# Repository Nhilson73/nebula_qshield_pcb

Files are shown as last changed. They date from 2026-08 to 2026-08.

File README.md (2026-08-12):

# Nebula Q-Shield® PCB

**Precision Fermentation Monitor** — PCB shield de 4 capas para el Arduino UNO Q, con sensores de fermentación, control de actuadores, HMI UART y trazabilidad integrada al ecosistema Nebula.

Built by [Cafelium SRL](https://github.com/Nhilson73) · Dominican Republic

> **Parte del ecosistema [Nebula Q-Shield — Arduino App Lab](https://github.com/Nhilson73/Nebula_ArduinoAPPLab_UNOQ)**
>
> **Awards:** I+D Lab INDOTEL 2025 · CREE Banreservas 2026 · Pitch4FUN 2026
>
> **Firmware source of truth:** [`Nhilson73/Nebula_ArduinoAPPLab_UNOQ`](https://github.com/Nhilson73/Nebula_ArduinoAPPLab_UNOQ). No usar `Nebula_UNOQ_ArduinoIDE_Core` para validaciones de pinout/hardware.
>
> **Estado actual (2026-08-12):** esquemático validado (ERC 0 violaciones), PCB en KiCad 10.0.5, factor de forma UNO Q inmutable, dimensiones **150 mm × 120 mm** (se amplió el ancho para la propuesta de placement de Gemini Spark), Fase 4 de potencia completa y Fase 5/6 de ruteo en progreso: DRC 0 violaciones, 72 nets desconectados restantes. Se ajustó `Signal_Default` a vía mínima 0.5/0.2 mm para mejorar conectividad GND. Ver `docs/INSIGHT_FABRICATION_ROADMAP.md`.

---

## ¿Qué es el Q-Shield®?

El Q-Shield® es un **PCB shield de 4 capas** que se monta sobre el Arduino UNO Q (STM32U585 MCU + Qualcomm QRB2210 MPU), convirtiendo la placa en un sistema completo de monitoreo y control de fermentación para café y cacao de especialidad.

Se fabrica como **una sola PCB** para los tres tiers. La diferencia entre tiers se logra poblando o dejando en DNP ciertos componentes; el firmware selecciona el tier en tiempo de compilación.

```
┌──────────────────────────────────────────────────────────────────┐
│                    NEBULA Q-SHIELD® PCB v1.0                     │
│                                                                  │
│  ┌──────────────┐  ┌──────────────┐  ┌──────────────────────┐   │
│  │ POTENCIA     │  │  ANALÓGICO    │  │     DIGITAL          │   │
│  │              │  │              │  │                      │   │
│  │ 12 V input   │  │ pH  (A0)     │  │ I2C bus (D20/D21)    │   │
│  │ Buck 12→5 V  │  │ ORP (A1)     │  │ HX711 (D2/D3)        │   │
│  │ LDO 5→3.3 V  │  │ Temp (A2)    │  │ GPS + RTC (I2C)      │   │
│  │ TVS + PTC    │  │ CO2 (A4)     │  │ RS485 bridge (Sig.)  │   │
│  │ Schottky     │  │ DO  (A5)     │  │ HMI UART             │   │
│  └──────────────┘  └──────────────┘  └──────────────────────┘   │
│                                                                  │
│  ┌──────────────────────────────────────────────────────────┐   │
│  │  ACTUADORES (opto-aislados) — Insight+                  │   │
│  │  Recirculación · Solenoide gas · Chiller                 │   │
│  └──────────────────────────────────────────────────────────┘   │
│                                                                  │
│  ┌──────────────────────────────────────────────────────────┐   │
│  │  CONECTOR ARDUINO UNO Q / R3 (32-pin shield header)      │   │
│  └──────────────────────────────────────────────────────────┘   │
└──────────────────────────────────────────────────────────────────┘
```

---

## Hardware Tier Model

Una sola PCB para los 3 tiers — los componentes no poblados (DNP) se seleccionan en fabricación:

| Tier | Sensores / Funciones | Actuadores | Placements poblados |
|---|---|---|---|
| **Essential®** | GPS (altitud), RTC/timestamp, temperatura, pH, ORP, HMI | — | 88 / 163 |
| **Insight®** | Essential + CO₂ (presión), DO, celdas de carga, I2C bus D20/D21 | Recirculación, solenoide gas, chiller | 137 / 163 |
| **Signature®** | Insight + densidad celular total (TCD) + activa (ACD) Hamilton vía RS485 | Igual que Insight | 146 / 163 |

- Convención DNP en el campo `DNP`: lista los tiers en los que el componente **no** se pobla.
- Canal de humedad y válvula PWM de gas quedan eliminados/DNP en todos los tiers.
- El pinout detallado de `J21` está en `docs/INSIGHT_FABRICATION_ROADMAP.md`.

---

## Componentes principales

| # | Componente | Interfaz | Tier |
|---|---|---|---|
| 1 | Sensor pH | Analógico A0 / I2C EZO | Essential+ |
| 2 | Sensor ORP | Analógico A1 / I2C EZO | Essential+ |
| 3 | Sensor temperatura | Analógico A2 | Essential+ |
| 4 | GPS u-blox SAM-M8Q (altitud por GPS) | I2C 0x42 | Essential+ |
| 5 | RTC DS3231 | I2C 0x68 | Essential+ |
| 6 | HMI UART 5" (Nextion/Stone/DWIN) | UART TX/RX | Todos |
| 7 | Celdas de carga + HX711 | Digital D2/D3 | Insight+ |
| 8 | Transductor presión CO₂ | Analógico A4 | Insight+ |
| 9 | Sensor oxígeno disuelto (DO) | Analógico A5 | Insight+ |
| 10 | Driver recirculación (half-bridge) | PWM/DIR D5/D6 | Insight+ |
| 11 | Solenoide gas CO₂/H₂ | GPIO D7 | Insight+ |
| 12 | Chiller (relé opto-aislado) | GPIO D8 | Insight+ |
| 13 | Sensores Hamilton TCD + ACD | RS485/Modbus | Signature |

---

## Diseño 100% Foolproof — 7 Capas de Protección

```
┌─────────────────────────────────────────────────────────┐
│  7. Firmware failsafe (watchdog, store-forward)         │
│  ┌─────────────────────────────────────────────────┐   │
│  │  6. Aislamiento galvánico (ISO7721, PC817)      │   │
│  │  ┌─────────────────────────────────────────┐   │   │
│  │  │  5. Protección térmica (shutdown auto)  │   │   │
│  │  │  ┌─────────────────────────────────┐   │   │   │
│  │  │  │  4. Limitación corriente (PTC)  │   │   │   │
│  │  │  │  ┌─────────────────────────┐   │   │   │   │
│  │  │  │  │  3. ESD/TVS (±8kV)      │   │   │   │   │
│  │  │  │  │  ┌─────────────────┐   │   │   │   │   │
│  │  │  │  │  │  2. Polaridad   │   │   │   │   │   │
│  │  │  │  │  │  ┌─────────┐   │   │   │   │   │   │
│  │  │  │  │  │  │1. Mecán.│   │   │   │   │   │   │
│  │  │  │  │  │  └─────────┘   │   │   │   │   │   │
│  │  │  │  │  └─────────────────┘   │   │   │   │   │
│  │  │  │  └─────────────────────────┘   │   │   │   │
│  │  │  └─────────────────────────────────┘   │   │   │
│  │  └─────────────────────────────────────────┘   │   │
│  └─────────────────────────────────────────────────┘   │
└─────────────────────────────────────────────────────────┘
```

- **Conectores keyed** — Físicamente imposible conectar al revés
- **Schottky SS34** — Protección polaridad inversa sin daño
- **TVS ESD IEC 61000-4-2 Level 4** — ±8 kV contacto, ±15 kV aire
- **PTC recuperable** — Auto-reset después de cortocircuito
- **Thermal shutdown** — Reguladores se apagan a 85°C y se recuperan
- **Opto-aislamiento** — MCU aislado de actuadores de potencia
- **Watchdog dual** — TPS3823 externo (1.6s) + IWDG interno (8s), poblado en TODOS los tiers
- **Aislamiento galvánico on-board** — SN6501 + AMC1301/ISO1541 por canal húmedo (pH, ORP, DO)

---

## Cumplimiento Normativo Europeo

| Directiva | Norma | Estado |
|---|---|---|
| **EMC** (2014/30/EU) | EN 55032 Clase B, EN 61000-4-2/3/4/5/6 | Diseñado |
| **RoHS 3** (2011/65/EU + 2015/863) | Soldadura SAC305, ENIG, sin Pb/Hg/Cd | Especificado |
| **WEEE** (2012/19/EU) | Categoría 6, registro por país | Pendiente registro |
| **RED** (2014/53/EU) | WiFi/BT via Arduino UNO Q cert. | Verificar con Arduino |
| **REACH** ((EC) 1907/2006) | Verificación SVHC proveedores | Pendiente |
| **Marcado CE** | Declaración de Conformidad | Post-ensayos |

---

## Estructura del Repositorio

```
nebula_qshield_pcb/
├── README.md                          # Este documento
├── .gitignore                         # Exclusiones KiCad/OS
│
├── docs/                              # Documentación de ingeniería
│   ├── 01_PCB_ARCHITECTURE.md         # Arquitectura completa del PCB
│   ├── 02_FOOLPROOF_DESIGN.md         # Diseño 100% Foolproof (7 capas)
│   ├── 03_EU_COMPLIANCE.md            # Cumplimiento normativo europeo
│   ├── 04_BOM_PRODUCTION.md           # BOM con part numbers Digi-Key/Mouser
│   ├── 05_POWER_BUDGET.md             # Análisis de presupuesto de potencia
│   ├── 06_PCB_LAYOUT_STACKUP.md       # Guías de layout y stackup 4 capas
│   ├── 07_KICAD_NETLIST.md            # Netlist KiCad y definiciones
│   ├── 08_MECHANICAL_ANALYSIS.md      # Análisis mecánico y compactación
│   ├── INSIGHT_FABRICATION_ROADMAP.md # Hoja de ruta JLCPCB para Insight
│   ├── UNO_Q_FORM_FACTOR.md           # Referencia inmutable del factor de forma UNO Q
│   ├── KICAD10_SSH_SETUP.md           # Guía SSH para clonar desde KiCad 10
│   └── DOCUMENTATION_UPDATE_AUDIT.md  # Auditoría de docs por actualizar
│
├── kicad/                             # Proyecto KiCad 10.0.5
│   ├── nebula_qshield.kicad_pro       # Proyecto principal
│   ├── nebula_qshield.kicad_sch       # Esquemático raíz (jerárquico)
│   ├── nebula_qshield.kicad_pcb       # Layout PCB (en progreso)
│   ├── power_management.kicad_sch     # Sub-hoja: reguladores y protección
│   ├── analog_acquisition.kicad_sch   # Sub-hoja: canales analógicos
│   ├── digital_i2c.kicad_sch          # Sub-hoja: bus I2C, HX711, RS485 bridge
│   ├── actuator_drivers.kicad_sch     # Sub-hoja: drivers de actuadores
│   ├── hmi_connectors.kicad_sch       # Sub-hoja: HMI UART y J21
│   ├── lib/                           # Librerías de símbolos y footprints
│   ├── production/                    # Salidas de fabricación
│   └── UNO_Q_rearchitecture_report.md # Reporte de re-arquitectura UNO Q
│
├── hardware/                          # Diseño mecánico
│   ├── enclosure/                     # Carcasa/enclosure IP54
│   └── cables/                        # Especificaciones de cables
│
├── test/                              # Testing y validación
│   ├── hil/                           # Hardware-in-the-Loop tests
│   └── validation/                    # Reportes de validación
│
└── tools/                             # Scripts Python de automatización
    ├── tier_counts.py                 # Conteos de componentes por tier
    ├── apply_tier_dnp4.py            # Aplicar propiedades DNP por tier
    ├── compare_pcb_to_netlist.py      # Verificar paridad PCB/netlist
    └── update_tier_comments.py       # Actualizar comentarios de tier
```

### Esquemáticos Jerárquicos

```
nebula_qshield.kicad_sch (raíz)
├── power_management.kicad_sch     → 12V protección, Buck 5V, LDO 3.3V, TPS3823 watchdog
├── analog_acquisition.kicad_sch   → pH/ORP/Temp/CO₂/DO + aislamiento galvánico
├── digital_i2c.kicad_sch          → I2C (D20/D21), HX711, RS485 Modbus bridge (Signature)
├── actuator_drivers.kicad_sch     → Recirculación, solenoide gas, chiller
└── hmi_connectors.kicad_sch       → HMI UART y shield header J21
```

---

## Especificaciones Técnicas

| Parámetro | Valor |
|---|---|
| **Dimensiones** | 125 mm × 120 mm (factor de forma Arduino UNO Q inmutable; el tamaño exterior puede variar) |
| **Capas** | 4 (Signal–GND–Power–Signal) |
| **Material** | FR-4 Tg 170°C |
| **Acabado** | ENIG (RoHS) |
| **Cobre** | 1 oz (35 μm) todas las capas |
| **Temperatura operativa** | -10°C a +55°C |
| **Alimentación** | 12V DC (Essential: 2A, Insight: 3A, Signature: 8A) |
| **Placements totales** | 163 (88 Essential / 137 Insight / 146 Signature) |
| **KiCad** | 10.0.5 |
| **IPC Class** | Clase 2 |

---

## Presupuesto de Potencia

| Tier | Potencia continua | Fuente recomendada |
|---|---|---|
| Essential® | 11 W | 12V 2A (24W) |
| Insight® | 23 W | 12V 3A (36W) |
| Signature® | 65 W | 12V 8A (96W) |

---

## Getting Started

### Requisitos

- [KiCad 10.0.5](https://www.kicad.org/download/)
- [Python 3.11+](https://www.python.org/) (para scripts de BOM/CPL)
- Cuenta GitHub con acceso al repositorio

### Clonar el proyecto

Opción A — terminal:

```bash
git clone git@github.com:Nhilson73/nebula_qshield_pcb.git
cd nebula_qshield_pcb/kicad
# Abrir nebula_qshield.kicad_pro con KiCad 10
```

Opción B — desde KiCad 10:

Ver `docs/KICAD10_SSH_SETUP.md` para configurar SSH y clonar directamente desde `File → Clone Project from Git Repository`.

### Validación del diseño

```bash
# ERC
docker run --rm -v "$PWD:/workspace" kicad/kicad:10.0.5 \
  kicad-cli sch erc --severity-all \
  /workspace/kicad/nebula_qshield.kicad_sch

# DRC error-level
docker run --rm -v "$PWD:/workspace" kicad/kicad:10.0.5 \
  kicad-cli pcb drc --severity-error \
  /workspace/kicad/nebula_qshield.kicad_pcb

# Paridad PCB/netlist (exportar primero el netlist XML)
docker run --rm -v "$PWD:/workspace" kicad/kicad:10.0.5 \
  kicad-cli sch export netlist --format kicadxml \
  -o /workspace/kicad/uno_q.xml /workspace/kicad/nebula_qshield.kicad_sch

docker run --rm -v "$PWD:/workspace" kicad/kicad:10.0.5 \
  python3 /workspace/tools/compare_pcb_to_netlist.py
```

### Generar archivos de fabricación

Desde KiCad 10:

```
File → Plot → Gerber
File → Fabrication Outputs → Drill Files
File → Fabrication Outputs → BOM
File → Fabrication Outputs → Footprint Position File
```

Los parámetros de fabricación JLCPCB están en `docs/INSIGHT_FABRICATION_ROADMAP.md` y `docs/04_BOM_PRODUCTION.md`.

---

## Pinout J21 de referencia (Insight)

| Pin | Función | Net |
|-----|---|-----|
| 1 | BOOT | NC |
| 2 | IOREF | NC |
| 3 | ~RESET | `/MCU_NRST` |
| 4 | +3V3 | `/3V3_RAIL` |
| 5 | +5V | `/5V_RAIL` |
| 6 | GND | `GND` |
| 7 | GND2 | `GND` |
| 8 | VIN | `/12V_RAIL` |
| 9 | A0/D14 | `/PH_ADC` |
| 10 | A1/D15 | `/ORP_ADC` |
| 11 | A2/D16 | `/TEMP_ADC` |
| 12 | A3/D17 | `/HUM_ADC` — DNP all tiers |
| 13 | A4/D18 | `/CO2_ADC` |
| 14 | A5/D19 | `/DO_ADC` |
| 15 | D0 | `/HMI_RX` |
| 16 | D1 | `/HMI_TX` |
| 17 | D2 | `/HX711_DOUT` |
| 18 | D3 | `/HX711_SCK` |
| 19 | D4 | `/MCU_WDI` |
| 20 | D5 | `/PUMP_PWM` |
| 21 | D6 | `/PUMP_DIR` |
| 22 | D7 | `/CO2_SOL_CTL` |
| 23 | D8 | `/CHILLER_CTL` |
| 24 | D9 | `/CO2_PWM` — DNP all tiers |
| 25 | D10 | `/RS485_IRQ` |
| 26 | D11 | NC |
| 27 | D12 | NC |
| 28 | D13 | `/LED_STATUS` |
| 29 | GND | `GND` |
| 30 | AREF | NC |
| 31 | D20/SDA | `/I2C_SDA` |
| 32 | D21/SCL | `/I2C_SCL` |

El pinout completo, mapa de tiers y hoja de ruta de fabricación están en `docs/INSIGHT_FABRICATION_ROADMAP.md`.

---

## Repositorios Relacionados

| Repositorio | Descripción |
|---|---|
| [Nebula_ArduinoAPPLab_UNOQ](https://github.com/Nhilson73/Nebula_ArduinoAPPLab_UNOQ) | Firmware MCU + Software MPU + Servicios Docker + Contratos L2. **Source of truth** para el pinout y lógica del Q-Shield. |
| **nebula_qshield_pcb** (este repo) | PCB shield para Arduino UNO Q (esquemáticos KiCad, BOM, compliance) |

---

## Licencia

Proprietary — Cafelium SRL. All rights reserved.

---

## Team

- **Nhilson** — Lead Architect
- **Drancés** — Co-founder
- **Alfredo** — Co-founder

Powered by the **Nebula Ecosystem™**: Nebula Terra® · Nebula Fermentation® · Nebula Originblok® · Nebula Marketplace®

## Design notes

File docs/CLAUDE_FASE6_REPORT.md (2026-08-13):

# Reporte Claude Code — Fase 6: cierre de desconectados y descongestión del bloque analógico

## Resumen ejecutivo

| | Antes | Después |
|---|---|---|
| Tamaño de board | 150 × 120 mm | **170 × 120 mm** |
| DRC violations | 0 | **0** |
| ERC violations | 0 | **0** |
| Unconnected items | 38 | **69** (ver por qué subió, abajo) |
| Bloque analógico | ~34×32 mm, ~59 componentes | reubicado en ~2 mm de aire real vs. 0.25 mm antes |

El pedido original eran los 38 pares desconectados que quedaron después de 8 rondas previas de scripts (`close_pairs_v4`…`v8`, ruteo manual de GND). Diagnostiqué que la mayoría de esos 38 no eran un problema de ruteo sino de **geometría real**: varios pads quedaban encajonados entre pines vecinos de otros componentes con ~0.25–0.45 mm de separación, insuficiente incluso para el ancho **mínimo legal del board**. No hay ruta, por más inteligente que sea el router, que entre ahí sin más aire o sin mover algo.

Con tu autorización moví el tamaño del board a 170×120 mm y reubiqué el bloque analógico completo (~59 componentes: T1–T3, U4–U13, R7–R18, R30–R33, D3–D8, D19–D24, C12–C24, C28–C30, TP1–TP2). Eso obligó a **rip-up y re-ruteo de las 183 conexiones** de ese bloque (no solo las 38 originales), porque mover un componente invalida todo el copper que ya tenía. De esas 183, el script cerró **117 (64%)** manteniendo DRC en 0 en todo momento; quedan **66 desconectadas del bloque analógico** más **3 de fuera de ese alcance** (69 total) — ver detalle abajo.

## Qué se entrega

1. **`tools/route_fase6.py`** — router propio (Dijkstra sobre grilla local F.Cu/B.Cu + transición por vía, con verificación geométrica exacta antes de comprometer cualquier track/vía) para cerrar pares `unconnected_items` reportados por `kicad-cli pcb drc`. Reemplaza la heurística de esquinas de `close_pairs_v8.py`, que se había estancado en los 38 pares sin poder avanzar más. Incluye:
   - Fallback a ancho reducido ("neck-down") cuando el ancho de netclass no entra, respetando el **mínimo real por netclass** de `kicad/nebula_qshield.kicad_dru` (no un piso genérico) — Power/HighCurrent nunca bajan de 0.5 mm, Analog/I2C no bajan de 0.25 mm, etc.
   - Fase de nudge (≤2 mm) de pasivos analógicos (`C20,C21,C23,R30,R31,R32`) con reconexión por jumper del pin que ya tenía copper — implementada pero en la práctica no tuvo éxito en ningún caso probado: el encajonamiento excede 2 mm en los casos donde se necesitaba.
   - Filtra pares `Zone`↔`Zone` que `kicad-cli` reporta de forma no determinística (ligado al orden de relleno de islas de plano) sin coordenada real de conexión.
   - Uso: `<python de KiCad> tools/route_fase6.py [board.kicad_pcb] [--dry-run] [--verbose]`. Corrido varias veces sobre el mismo board sigue cerrando pares adicionales (cada pasada reduce algo la congestión para la siguiente).

2. **`tools/replan_analog_block.py`** — script de re-layout:
   - Extiende `Edge.Cuts` y las 2 zonas full-board (GND en 2 capas, `/12V_RAIL`) 20 mm a la derecha (150.1 → 170.1 mm).
   - **No desplaza** la columna de conectores J2/J3/J5/J15–J19 ni el sector de relés/actuadores (K1, K2, U17, U20…): entre el bloque analógico y esa columna pasan ~7 nets ajenas (bus RS485, interfaz HX711) a distintas alturas; moverla hubiera obligado a re-rutear todo eso también, muy por fuera del pedido.
   - Reempaquetado (shelf-packing por tamaño descendente) del bloque analógico en un corredor en **forma de L**: franja superior (como antes, arriba del courtyard de J21) + franja angosta a la derecha del courtyard de J21 (que es el área de acoplamiento UNO Q, inmutable) hasta antes de J16/J17/D10. Separación entre componentes 2–4× la que tenían antes (0.4–1.2 mm según tamaño, vs. ~0.25 mm).
   - Rip-up de: todo el copper propio de las ~48 nets del bloque analógico; la porción local de GND/`/3V3_RAIL`/`/5V_RAIL`/`/12V_RAIL` dentro del área vieja/nueva del cluster; y los tracks de paso (`HX711_EN/EP/SP`, `HX711_DOUT`, `RS485_A/B`, `MOTOR_VS`, `I2C_SCL`) que cruzaban el nuevo corredor.
   - Uso: `<python de KiCad> tools/replan_analog_block.py [board.kicad_pcb]`.

3. `kicad/nebula_qshield.kicad_pcb` modificado: 170×120 mm, bloque analógico reubicado, 117 de 183 conexiones de ese bloque re-ruteadas, **0 violaciones DRC**.

## Validación

```
kicad-cli pcb drc --severity-error --refill-zones -o kicad/nebula_qshield-drc.rpt kicad/nebula_qshield.kicad_pcb
  → Found 0 violations
  → Found 69 unconnected items

kicad-cli sch erc --severity-all -o kicad/nebula_qshield-erc.rpt kicad/nebula_qshield.kicad_sch
  → Found 0 violations
```

(Corrido con `kicad-cli.exe` 10.0.5 local — mismo binario que la imagen `kicad/kicad:10.0.5`; no hizo falta Docker en este entorno Windows.)

## Por qué el número de desconectados subió de 38 a 69 en vez de bajar a 0

No es una regresión: mover cualquier componente invalida **todo** el copper que tenía, no solo el que estaba roto. Al reubicar el bloque analógico completo, las 183 conexiones de esas ~48 nets quedaron sin rutear (no solo las 38 que ya estaban rotas) y hubo que re-hacerlas desde cero con el layout nuevo. El router cerró 117 de esas 183 (64%) sin generar ninguna violación DRC en el proceso — corrí el ciclo completo 3 veces sobre el board real; la tercera pasada ya no cerró ninguna adicional (estancamiento).

## Los 69 que quedan — desglose y causa raíz

**66 dentro del bloque analógico recién reubicado** (`/Analog Acquisition/*`, más `GND`/`/3V3_RAIL`/`/5V_RAIL`/`/12V_RAIL` locales a ese bloque): la causa dominante es que el corredor en L tiene un **"cuello de botella"** entre la franja superior (filas de T1–T3, U4–U13) y la franja inferior derecha (R30–33, C12–C24, D19–D24) — son ~18 mm de ancho entre el courtyard de J21 y J5/J16/J17. El empaquetador ordenó los componentes por tamaño (para que entraran los 59), no por qué net comparten con qué vecino, así que varias conexiones terminaron necesitando cruzar ese cuello de botella en vez de quedar entre componentes contiguos. Ejemplos: `T1↔D19/D20`, `T2↔U8`, `U6↔U4`, varios `RX_FILT`/`RX_SIG`/`GND_ISO_*` entre la fila de arriba y la de abajo.

**Recomendación concreta:** un empaquetador que agrupe por conectividad (ej. cada transformador T*junto con su AMC1301/diodos asociados en la misma sub-región) en vez de solo por tamaño reduciría esto sustancialmente. No lo implementé por tiempo — el packing actual (`pack_cluster` en `replan_analog_block.py`) es un buen punto de partida para iterar: la función ya soporta regiones múltiples, solo falta una heurística de agrupamiento consciente de netlist antes del sort por tamaño.

**3 fuera del bloque analógico, con atención más urgente** (son subsistemas que no pedían tocar, pero `replan_analog_block.py` tuvo que ripear el tramo que cruzaba el nuevo corredor):
- `/Digital & I2C/RS485_B` — bus RS485.
- `/Digital & I2C/HX711_SP`, `/Digital & I2C/HX711_EN` — interfaz de la celda de carga HX711.
- (`HX711_EP` y `HX711_DOUT` sí volvieron a cerrar en el proceso; `HX711_SP`/`EN`/`RS485_B` no.)

Estas tres no son "difíciles" geométricamente — simplemente no llegó a intentarlas con éxito en las 3 pasadas antes de estancarse. Correr `tools/route_fase6.py` una vez más (o revisar a mano esos 3 tramos, son tracks largos y rectos en un área relativamente despejada) debería cerrarlas sin drama.

**Del set original de 38, siguen sin cerrar 4** (genuinamente difíciles, no relacionadas con el bloque analógico):
- `/Actuator Drivers/MOTOR_HO` (Q1↔U17): la misma limitación geométrica de siempre, sin espacio extra ahí porque no se tocó esa zona.
- `/CO2_SOL_CTL` (J21↔R26) y `/I2C_SCL` (R37↔J21): rutas largas cerca del header J21, empeoradas por la congestión del área que sigue igual (no es parte del bloque analógico que se reubicó).
- `/3V3_RAIL` (U22 pad 14): el caso que documenté en detalle — el pad queda a 0.45 mm de los pines vecinos del mismo chip (RS485_RO/XTAL1) en ambas direcciones verticales, y `/3V3_RAIL` es netclass **Power**, que exige mínimo 0.5 mm de ancho por regla custom (`Power_Rails` en el `.kicad_dru`) — ni con neck-down entra. Requiere mover el footprint de `U22` (fuera del alcance permitido) o aceptar una excepción de ancho documentada explícitamente en el design rule.

## Notas para quien continúe

- El corredor en L está documentado con sus 4 esquinas exactas en `replan_analog_block.py` (`REGION_1`, `REGION_2`) — están ajustadas al milímetro contra los courtyards reales de J21/J2/J3/J5/J16/J17/D10 (los descubrí por prueba y error, varias iteraciones dieron falsos "courtyard overlap" hasta calzar los márgenes). No los toques sin volver a chequear esos courtyards.
- `tools/route_fase6.py` es reutilizable tal cual para cualquier ronda futura de cierre — solo necesita un `.kicad_pcb` + su `.kicad_pro`/`.kicad_dru` con el mismo nombre base al lado (para que `kicad-cli` resuelva las reglas custom del proyecto).
- **Importante para testing**: si copiás el `.kicad_pcb` a otro nombre para probar, copiá también el `.kicad_pro` y el `.kicad_dru` con el mismo basename — si no, `kicad-cli` aplica reglas genéricas de KiCad en vez de las custom del proyecto y reporta violaciones falsas (así lo descubrí: 217 violaciones falsas por esto en una prueba temprana).

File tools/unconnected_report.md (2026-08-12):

# Análisis de nets desconectadas
**Total pares:** 40

## Resumen por red
| Net | Pares |
| --- | --- |
| GND | 5 |
| /12V_RAIL | 5 |
| /5V_RAIL | 4 |
| /3V3_RAIL | 2 |
| /Analog Acquisition/VDD_ISO_ORP | 2 |
| /Analog Acquisition/PH_ATT | 2 |
| /Analog Acquisition/ORP_ATT | 1 |
| /HUM_ADC | 1 |
| /CO2_SOL_CTL | 1 |
| /Analog Acquisition/GND_ISO_PH | 1 |
| /Analog Acquisition/ORP_SIG | 1 |
| /I2C_SCL | 1 |
| /Analog Acquisition/PH_BUF | 1 |
| /Analog Acquisition/VDD_ISO_PH | 1 |
| /Analog Acquisition/VDD_ISO_DO | 1 |
| /Analog Acquisition/DO_FILT | 1 |
| /Actuator Drivers/MOTOR_HO | 1 |
| /Analog Acquisition/DO_SEC_B | 1 |
| /Analog Acquisition/CO2_SIG | 1 |
| /Analog Acquisition/DO_BUF | 1 |
| /Analog Acquisition/DO_SIG | 1 |
| /Analog Acquisition/SN_D1_DO | 1 |
| /Analog Acquisition/SN_D2_DO | 1 |
| /Analog Acquisition/SN_D1_ORP | 1 |
| /Analog Acquisition/SN_D2_ORP | 1 |
| /Analog Acquisition/SN_D2_PH | 1 |

## Detalle de pares (Net, Tipo_A, Ref_A, Capa_A, x_A, y_A -> Tipo_B, Ref_B, Capa_B, x_B, y_B)
| Net | A | Ref A | Capa A | xA | yA | B | Ref B | Capa B | xB | yB |
| --- | --- | --- | --- | --- | --- | --- | --- | --- | --- | --- |
| /Analog Acquisition/ORP_ATT | Pad 1 | R32 | F.Cu | 71.82 | 31.87 | Track | None | B.Cu | 67.0102 | 35.1403 |
| /HUM_ADC | Pad 1 | C23 | F.Cu | 71.83 | 33.11 | Track | None | F.Cu | 65.07 | 31.87 |
| GND | Via | None | F.Cu - B.Cu | 4.4598 | 25.9154 | Pad 2 | C11 | F.Cu | 3.79 | 24.86 |
| GND | Via | None | F.Cu - B.Cu | 63.6826 | 19.1636 | Pad 5 | U9 | F.Cu | 65.505 | 20.875 |
| GND | Pad 2 | C21 | F.Cu | 68.29 | 33.11 | Track | None | F.Cu | 71.2772 | 33.8472 |
| GND | Track | None | F.Cu | 72.79 | 33.11 | Pad 2 | C14 | F.Cu | 75.04 | 32.11 |
| GND | Pad 2 | D5 | F.Cu | 89.35 | 21.9 | Track | None | F.Cu | 88.185 | 26.0062 |
| /3V3_RAIL | Pad 14 | U22 | F.Cu | 22.8625 | 104.025 | Via | None | F.Cu - B.Cu | 21.6224 | 104.1817 |
| /3V3_RAIL | Track | None | F.Cu | 67.445 | 22.1518 | Via | None | F.Cu - B.Cu | 72.3983 | 23.2477 |
| /Analog Acquisition/VDD_ISO_ORP | Via | None | F.Cu - B.Cu | 70.35 | 28.55 | Pad 1 | U9 | F.Cu | 61.695 | 25.825 |
| /Analog Acquisition/VDD_ISO_ORP | Via | None | F.Cu - B.Cu | 70.35 | 28.55 | Via | None | F.Cu - B.Cu | 84.3898 | 28.5614 |
| /CO2_SOL_CTL | PTH pad 22 | J21 | F.Cu - B.Cu | 41.66 | 86.36 | Via | None | F.Cu - B.Cu | 105.0 | 95.51 |
| /Analog Acquisition/GND_ISO_PH | Track | None | F.Cu | 85.54 | 31.86 | Via | None | F.Cu - B.Cu | 69.57 | 31.87 |
| /Analog Acquisition/ORP_SIG | Via | None | F.Cu - B.Cu | 78.57 | 20.12 | Track | None | F.Cu | 89.6 | 20.6 |
| /I2C_SCL | Pad 1 | R37 | F.Cu | 68.055 | 96.0 | Track | None | B.Cu | 68.58 | 86.36 |
| /Analog Acquisition/PH_BUF | Via | None | F.Cu - B.Cu | 68.34 | 31.87 | Track | None | F.Cu | 83.1227 | 11.825 |
| /Analog Acquisition/VDD_ISO_PH | Track | None | F.Cu | 83.695 | 20.0977 | Track | None | F.Cu | 64.2719 | 27.4719 |
| /5V_RAIL | Via | None | F.Cu - B.Cu | 41.0 | 1.3 | Track | None | F.Cu | 19.4 | 7.87 |
| /5V_RAIL | Track | None | F.Cu | 84.8125 | 21.9 | Track | None | F.Cu | 78.05 | 18.05 |
| /5V_RAIL | Via | None | F.Cu - B.Cu | 85.1261 | 24.8836 | Track | None | F.Cu | 84.8125 | 21.9 |
| /5V_RAIL | Via | None | F.Cu - B.Cu | 91.7685 | 26.4338 | Track | None | F.Cu | 85.1261 | 24.8836 |
| /Analog Acquisition/VDD_ISO_DO | Track | None | F.Cu | 75.35 | 30.05 | Track | None | F.Cu | 64.9261 | 33.2639 |
| /Analog Acquisition/DO_FILT | Track | None | F.Cu | 78.58 | 32.86 | Track | None | F.Cu | 69.57 | 30.62 |
| /Actuator Drivers/MOTOR_HO | Via | None | F.Cu - B.Cu | 110.4135 | 68.7984 | Pad 7 | U17 | F.Cu | 117.0714 | 75.1659 |
| /12V_RAIL | Zone | None | In2.Cu | -8.0 | -2.0 | Via | None | F.Cu - B.Cu | -8.0 | -2.0 |
| /12V_RAIL | Pad 1 | R4 | F.Cu | 2.82 | 22.37 | Track | None | F.Cu | 7.3441 | 24.4989 |
| /12V_RAIL | Via | None | F.Cu - B.Cu | 10.225 | 24.0 | Track | None | F.Cu | 14.925 | 23.4563 |
| /12V_RAIL | Track | None | F.Cu | 14.925 | 23.4563 | Via | None | F.Cu - B.Cu | 14.4 | 20.15 |
| /12V_RAIL | Zone | None | In2.Cu | -8.0 | -2.0 | Zone | None | In2.Cu | -8.0 | -2.0 |
| /Analog Acquisition/DO_SEC_B | Pad 6 | T3 | F.Cu | 75.51 | 6.81 | Via | None | F.Cu - B.Cu | 63.65 | 31.1 |
| /Analog Acquisition/CO2_SIG | Via | None | F.Cu - B.Cu | 89.0 | 24.1 | Via | None | F.Cu - B.Cu | 75.07 | 27.87 |
| /Analog Acquisition/PH_ATT | Pad 2 | R31 | F.Cu | 70.59 | 31.87 | Track | None | B.Cu | 68.955 | 29.87 |
| /Analog Acquisition/PH_ATT | Pad 2 | R31 | F.Cu | 70.59 | 31.87 | Pad 2 | U6 | F.Cu | 84.965 | 19.575 |
| /Analog Acquisition/DO_BUF | Pad 2 | U13 | F.Cu | 80.215 | 27.325 | Track | None | F.Cu | 74.465 | 20.875 |
| /Analog Acquisition/DO_SIG | Track | None | F.Cu | 89.35 | 27.6 | Pad 1 | R13 | F.Cu | 67.32 | 30.62 |
| /Analog Acquisition/SN_D1_DO | Via | None | F.Cu - B.Cu | 56.2625 | 30.05 | Via | None | F.Cu - B.Cu | 75.71 | 18.55 |
| /Analog Acquisition/SN_D2_DO | Via | None | F.Cu - B.Cu | 80.39 | 18.05 | Pad 5 | U12 | F.Cu | 58.3375 | 28.15 |
| /Analog Acquisition/SN_D1_ORP | Via | None | F.Cu - B.Cu | 66.26 | 18.05 | Pad 3 | U8 | F.Cu | 84.8125 | 27.55 |
| /Analog Acquisition/SN_D2_ORP | Pad 5 | U8 | F.Cu | 87.0875 | 25.65 | Track | None | F.Cu | 71.34 | 18.05 |
| /Analog Acquisition/SN_D2_PH | Pad 5 | U5 | F.Cu | 87.0875 | 21.9 | Pad 3 | T1 | F.Cu | 62.09 | 18.05 |

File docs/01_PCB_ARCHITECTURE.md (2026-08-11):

# Nebula Q-Shield® — Arquitectura PCB Completa

> **Estado (2026-08-11):** board 125 × 120 mm, DRC/ERC 0, 47 nets desconectadas en Fase 5. Ver `docs/INSIGHT_FABRICATION_ROADMAP.md`.
>
> **Documento:** NQS-ARCH-001 · **Rev:** 1.0 · **Fecha:** Mayo 2026
>
> **Clasificación:** Ingeniería — Diseño de Hardware
>
> **Normativas aplicables:** IPC-2221B, IPC-7351C, IEC 61010-1, EN 61326-1

---

## 1. Especificaciones Generales del PCB

### 1.1 Parámetros Físicos

| Parámetro | Valor | Justificación |
|---|---|---|
| **Dimensiones** | 125 × 120 mm (puede variar) | Factor de forma para acople con Arduino UNO Q; el patrón UNO Q es inmutable |
| **Capas** | 4 (Signal–GND–Power–Signal) | EMC Clase B, aislamiento analógico/digital |
| **Espesor total** | 1.6 mm ± 10% | Estándar IPC-2221B |
| **Material base** | FR-4 Tg 170°C (IT-180A o equivalente) | Operación hasta +55°C ambiente |
| **Acabado superficial** | ENIG (Electroless Nickel Immersion Gold) | RoHS, soldabilidad, longevidad |
| **Máscara de soldadura** | Verde LPI, ambos lados | Estándar industrial |
| **Serigrafía** | Blanca, ambos lados | Identificación de componentes |
| **Peso de cobre** | 1 oz (35 μm) capas externas, 1 oz internas | Capacidad de corriente actuadores |
| **Ancho mín. de pista** | 0.2 mm (señal), 0.5 mm (potencia) | IPC Clase 2 |
| **Espacio mín. entre pistas** | 0.2 mm (señal), 0.3 mm (potencia) | IPC-2221B clearance |
| **Taladro mínimo** | 0.3 mm (vías), 0.8 mm (THT) | Fabricación estándar |
| **Impedancia controlada** | No requerida (señales < 1 MHz) | Frecuencias bajas |

### 1.2 Stackup de 4 Capas

```
┌────────────────────────────────────────────────────────────┐
│  CAPA 1 (TOP)   — Señales + Componentes SMD               │  35 μm Cu
├────────────────────────────────────────────────────────────┤
│  Prepreg 7628   — 0.2 mm                                   │  Dieléctrico
├────────────────────────────────────────────────────────────┤
│  CAPA 2 (GND)   — Plano de tierra continuo                 │  35 μm Cu
├────────────────────────────────────────────────────────────┤
│  Core FR-4      — 0.8 mm                                   │  Dieléctrico
├────────────────────────────────────────────────────────────┤
│  CAPA 3 (PWR)   — Planos de potencia (12V, 5V, 3.3V)      │  35 μm Cu
├────────────────────────────────────────────────────────────┤
│  Prepreg 7628   — 0.2 mm                                   │  Dieléctrico
├────────────────────────────────────────────────────────────┤
│  CAPA 4 (BOT)   — Señales + Componentes SMD               │  35 μm Cu
└────────────────────────────────────────────────────────────┘
         Espesor total: ~1.6 mm
```

**Justificación del plano GND continuo (Capa 2):**
- Retorno de corriente de baja impedancia para todas las señales analógicas
- Blindaje electromagnético entre señales TOP y planos de potencia
- Reducción de EMI radiada para cumplimiento EN 55032 Clase B

---

## 2. Bloques Funcionales

### 2.1 Bloque de Potencia (Power Management)

#### 2.1.1 Entrada de Alimentación 12V DC

```
                            Foolproof Chain
    JACK DC 12V ──►[D_TVS SMAJ15A]──►[F1 PTC 3A]──►[D_SCHOTTKY SS34]──► 12V_RAIL
                    Protección        Fusible          Polaridad
                    transitorio       recuperable      inversa
                    ±15V clamp        I_hold=1.1A      V_f=0.5V
                                      I_trip=2.2A
```

| Componente | Referencia | Valor | Encapsulado | Función |
|---|---|---|---|---|
| D1 | SMAJ15A | 15V TVS bidireccional | SMA | Protección transitorio/ESD entrada |
| F1 | MF-MSMF110 | PTC 1.1A hold / 2.2A trip | 1812 | Fusible recuperable sobrecorriente |
| D2 | SS34 | Schottky 3A 40V | SMA | Protección polaridad inversa |
| C1 | Cerámico MLCC | 100 μF / 25V | 1210 | Desacoplo entrada |
| C2 | Electrolítico | 470 μF / 25V | Ø10×12.5 | Reserva energética transitoria |

#### 2.1.2 Regulador 5V — Buck Converter

```
    12V_RAIL ──►[TPS54302 Buck]──► 5V_RAIL (3A max)
                  │
                  ├── L1: 4.7 μH / 4A (Würth 744043004700)
                  ├── C_in: 22 μF × 2 ceramics (X5R, 25V)
                  ├── C_out: 47 μF × 2 ceramics (X5R, 10V)
                  ├── R_top: 100 kΩ (feedback divider)
                  ├── R_bot: 24.9 kΩ (Vout = 0.596 × (1 + R_top/R_bot) ≈ 5.0V)
                  └── C_boot: 100 nF (bootstrap)
```

| Componente | Referencia | Valor | Encapsulado | Función |
|---|---|---|---|---|
| U1 | TPS54302DDCR | Buck 3A, 4.5–28V in | SOT-23-6 | Regulador 12V → 5V |
| L1 | 744043004700 | 4.7 μH / 4A sat | 4×4×2 mm | Inductor de potencia |
| C3, C4 | X5R 25V | 22 μF | 0805 | Capacitor entrada buck |
| C5, C6 | X5R 10V | 47 μF | 0805 | Capacitor salida buck |
| R1 | — | 100 kΩ ±1% | 0402 | Feedback superior |
| R2 | — | 24.9 kΩ ±1% | 0402 | Feedback inferior |
| C7 | — | 100 nF | 0402 | Bootstrap |

#### 2.1.3 Regulador 3.3V — LDO

```
    5V_RAIL ──►[AMS1117-3.3]──► 3.3V_RAIL (800 mA max)
                  │
                  ├── C_in: 10 μF ceramic (X5R, 10V)
                  └── C_out: 22 μF ceramic (X5R, 10V) + 10 μF tantálum
```

| Componente | Referencia | Valor | Encapsulado | Función |
|---|---|---|---|---|
| U2 | AMS1117-3.3 | LDO 3.3V / 800 mA | SOT-223 | Regulador 5V → 3.3V |
| C8 | X5R 10V | 10 μF | 0805 | Desacoplo entrada LDO |
| C9 | X5R 10V | 22 μF | 0805 | Estabilidad salida LDO |
| C10 | Tantálum | 10 μF / 10V | 1206 | ESR serie estabilidad |

#### 2.1.4 Indicadores de Estado de Potencia

| LED | Color | Función | Resistor (3.3V) |
|-----|---|---|---|
| LED_12V | Rojo | Presencia 12V rail | 4.7 kΩ (vía divisor) |
| LED_5V | Verde | 5V rail OK | 330 Ω |
| LED_3V3 | Azul | 3.3V rail OK | 100 Ω |

---

### 2.2 Bloque de Adquisición Analógica (6 canales)

#### 2.2.1 Arquitectura por Canal

Cada canal analógico implementa la cadena de señal completa:

```
    SENSOR ──►[CONECTOR]──►[ESD TVS]──►[RC FILTER]──►[OP-AMP BUFFER]──►[ADC STM32]
               BNC/JST      PESD5V0     R=1kΩ          MCP6002          12-bit
               IP67          < 1 pF      C=100nF        Rail-to-Rail     Oversampling ×8
                             5V clamp    f_c = 1.59 kHz  Unity gain
```

#### 2.2.2 Detalle por Canal Analógico

##### Canal A0 — pH (Essential+)

| Componente | Ref | Valor | Función |
|---|-----|---|---|
| J1 | BNC hembra | — | Conector sonda pH (con aislamiento) |
| D3 | PESD5V0S1BSF | 5V TVS | Protección ESD IEC 61000-4-2 Level 4 |
| R3 | — | 1 kΩ ±1% | Filtro RC antialiasing |
| C11 | — | 100 nF X7R | Filtro RC (f_c ≈ 1.59 kHz) |
| U3A | MCP6002-I/SN | Rail-to-rail op-amp | Buffer impedancia (Z_in > 10 MΩ) |
| R4 | — | 10 MΩ | Pull-down bias (evita flotante sin sensor) |

**Nota pH:** La sonda pH genera señales de muy alta impedancia (~100 MΩ). El buffer op-amp es **crítico** para evitar errores de lectura. Para producción con Atlas EZO, el circuito analógico se bypasea y se usa I2C (0x63).

##### Canal A1 — ORP (Essential+)

Idéntico al canal pH, con conector BNC separado (J2). Dirección I2C Atlas: 0x62.

##### Canal A2 — Presión CO₂ (Insight+)

| Componente | Ref | Valor | Función |
|---|-----|---|---|
| J3 | JST-XH 3-pin | — | Conector transductor presión (VCC, OUT, GND) |
| D4 | PESD5V0S1BSF | 5V TVS | Protección ESD |
| R5, C12 | 1 kΩ / 100 nF | RC filter | Antialiasing |
| U3B | MCP6002 (canal B) | Buffer | Impedancia matching |
| R6, R7 | 10 kΩ / 10 kΩ | Divisor opcional | Escalado 4.5V → 3.3V si necesario |

**Señal transductor:** 0.5–4.5V (ratiométrico a 5V VCC). Mapeo lineal:
- 0.5V = 0 PSI (0 kPa)
- 4.5V = 30 PSI (207 kPa)

##### Canal A3 — Oxígeno Disuelto (Insight+)

Idéntico a canal pH (alta impedancia electroquímica). Conector BNC (J4). I2C Atlas: 0x61.

##### Canal A4 — Temperatura NTC (Essential+)

| Componente | Ref | Valor | Función |
|---|-----|---|---|
| J5 | JST-XH 2-pin | — | Conector NTC 10K |
| R8 | 10 kΩ ±1% | — | Resistencia serie (divisor de tensión) |
| C13 | 100 nF X7R | — | Filtro paso bajo |
| D5 | PESD3V3S1BSF | 3.3V TVS | Protección ESD (señal 0–3.3V) |

**Circuito NTC:** Divisor de tensión con R_serie = 10 kΩ. Steinhart-Hart en firmware.

```
    3.3V ──[R8 = 10kΩ]──┬──► A4 (ADC)
                         │
                        [NTC 10kΩ]
                         │
                        GND
```

##### Canal A5 — Humedad SHT30 (Signature)

| Componente | Ref | Valor | Función |
|---|-----|---|---|
| J6 | JST-XH 3-pin | — | Conector sensor humedad (VCC, OUT, GND) |
| D6 | PESD3V3S1BSF | 3.3V TVS | Protección ESD |
| R9, C14 | 1 kΩ / 100 nF | RC filter | Antialiasing |

#### 2.2.3 Aislamiento Galvánico — Sensores Electroquímicos

Los sensores pH, ORP y DO comparten el mismo líquido (mosto de fermentación). Sin aislamiento, se generan **ground loops** que corrompen las lecturas.

**Solución dual:**

1. **Con Atlas Scientific EZO (producción):** Cada carrier board ISCCB-2 proporciona aislamiento galvánico integrado (>1 kV DC). Sin componentes adicionales en el Q-Shield.

2. **Con sensores analógicos (prototipo):** El Q-Shield incluye aislamiento en la PCB:

```
    SONDA pH ──►[ISO7721 Digital Isolator]──► I2C aislado
                 o
    SONDA pH ──►[ADUM3151 ADC aislado]──► SPI aislado ──► MCU
```

| Componente | Ref | Valor | Función |
|---|-----|---|---|
| U4 | ISO7721DR | 2-ch digital isolator, 100 Mbps | Aislamiento I2C (para Atlas EZO) |
| U5 | Si8661BA | 6-ch digital isolator | Alternativa multi-canal |
| C15–C18 | 100 nF × 4 | — | Desacoplo lados aislados (2 por lado) |

**Especificación aislamiento:**
- Voltaje de aislamiento: >2.5 kV RMS (1 min)
- CMTI (Common Mode Transient Immunity): >25 kV/μs
- Cumple UL 1577, CSA, IEC 60747-5-5

---

### 2.3 Bloque I2C (Bus Digital)

#### 2.3.1 Topología del Bus

```
    STM32U585 I2C1 ──[R_PU 4.7kΩ to 3.3V]──┬──► GPS (0x42)
         SDA, SCL                             ├──► Cell Density (0x30)
                                              ├──► RTC DS3231 (0x68)
                                              ├──► EZO-pH (0x63) *opcional
                                              ├──► EZO-ORP (0x62) *opcional
                                              ├──► EZO-DO (0x61) *opcional
                                              └──► EZO-RTD (0x66) *opcional
```

#### 2.3.2 Componentes I2C

| Componente | Ref | Función | Notas |
|---|-----|---|---|
| R10, R11 | 4.7 kΩ | Pull-up SDA/SCL a 3.3V | Para bus 400 kHz (Fast Mode) |
| D7, D8 | PESD3V3S2USF | ESD dual-line protection | IEC 61000-4-2 Level 4 |
| J7 | JST-SH 4-pin (Qwiic compatible) | Conector GPS SAM-M8Q | VCC/GND/SDA/SCL |
| J8 | JST-SH 4-pin | Conector RTC DS3231 | VCC/GND/SDA/SCL |
| J9 | JST-SH 4-pin | Conector Cell Density | VCC/GND/SDA/SCL |
| J10–J13 | JST-SH 4-pin | Conectores Atlas EZO × 4 | Aislados vía U4/U5 |

#### 2.3.3 Protección del Bus I2C

- **ESD:** PESD3V3S2USF (doble línea SDA/SCL) — capacitancia < 0.5 pF, sin degradar señal a 400 kHz
- **Pull-ups:** 4.7 kΩ a 3.3V (calculados para 400 kHz con capacitancia total de bus ~200 pF)
- **Longitud máxima de bus:** 1 metro (con cables apantallados)
- **Repetidor I2C:** PCA9515A disponible como opción si la longitud del bus excede 1 m

---

### 2.4 Bloque Digital — HX711 (Load Cell ADC)

```
    CELDA DE CARGA ──►[HX711 24-bit ADC]──► D2 (DOUT) / D3 (SCK) ──► STM32
         (4 hilos)     ┌────────────────┐
         E+, E-, S+, S-│ Ganancia: 128  │
                        │ Rate: 80 SPS   │
                        │ VCC: 5V        │
                        └────────────────┘
```

| Componente | Ref | Valor | Función |
|---|-----|---|---|
| U6 | HX711 | 24-bit ADC, 80 SPS | ADC de precisión para celda de carga |
| J14 | Terminal block 4-pin | — | Conector celda de carga (E+/E-/S+/S-) |
| C19 | 100 nF | — | Desacoplo VCC HX711 |
| C20 | 10 μF | — | Filtro alimentación HX711 |
| R12 | 10 kΩ | Pull-up DOUT | Evita flotante durante arranque |

---

### 2.5 Bloque de Actuadores

#### 2.5.1 Driver de Motor — Bomba Peristáltica (Insight+)

```
    MCU D5 (PWM) ──►[PC817 Optoacoplador]──►[IR2104 Half-Bridge]──► MOTOR 12V
    MCU D4 (DIR) ──►[PC817 Optoacoplador]──►[IR2104 Half-Bridge]──► (bidireccional)
```

| Componente | Ref | Valor | Función |
|---|-----|---|---|
| U7 | IR2104SPBF | Half-bridge driver, 600V/250mA | Driver motor bomba |
| Q1, Q2 | IRLZ44NPBF | N-MOSFET 55V/47A, logic-level | Interruptores de potencia |
| U8, U9 | PC817X2NIP | Optoacoplador dual | Aislamiento MCU ↔ potencia |
| D9, D10 | SS34 | Schottky 3A | Diodos flyback motor |
| R13–R16 | 1 kΩ | — | Limitadores corriente base optoacopladores |
| C21 | 100 nF | — | Desacoplo VCC driver |

#### 2.5.2 Relays — Chiller y Solenoide CO₂

```
    MCU D6 ──►[R 1kΩ]──►[PC817]──►[RELAY K1]──► CHILLER 12V (Signature)
    MCU D7 ──►[R 1kΩ]──►[PC817]──►[RELAY K2]──► SOLENOIDE CO₂ NC (Insight+)
```

| Componente | Ref | Valor | Función |
|---|-----|---|---|
| K1 | HF46F-12-HS1 | Relay 12V, 5A/250VAC | Chiller relay |
| K2 | HF46F-12-HS1 | Relay 12V, 5A/250VAC | CO₂ solenoide relay |
| D11, D12 | 1N4148W | Diodo flyback | Protección bobina relay |
| Q3, Q4 | 2N7002 | N-MOSFET SOT-23 | Driver relay (con optoacoplador) |
| U10, U11 | PC817X1NIP | Optoacoplador | Aislamiento MCU ↔ relay |
| R17–R20 | 1 kΩ | — | Limitadores corriente |

#### 2.5.3 Regulador Flujo CO₂ PWM (Insight+)

```
    MCU D9 (PWM) ──►[RC Filter]──►[Op-Amp]──►[MOSFET]──► Válvula proporcional
                    R=10kΩ          MCP6002    IRLZ44N     0–12V proporcional
                    C=100nF         Gain=3.6x
```

| Componente | Ref | Valor | Función |
|---|-----|---|---|
| R21 | 10 kΩ | — | Filtro RC PWM-to-analog |
| C22 | 100 nF | — | Filtro RC (f_c = 159 Hz) |
| U3C | MCP6002 | Non-inverting amp | Escalar 3.3V PWM → 12V gate |
| Q5 | IRLZ44NPBF | N-MOSFET | Driver válvula proporcional |
| D13 | SS34 | Schottky | Flyback válvula |

---

### 2.6 Bloque de HMI (Human-Machine Interface)

#### 2.6.1 Conexión HMI UART

```
    MCU (D0/D1 UART) ──►[Q-Shield J_HMI JST-XH 4P]──►[Cable JST-XH]──► Nextion/Stone 5"
```

| Componente | Ref | Función |
|---|-----|---|
| J_HMI | JST-XH 4-pin (B4B-XH-A) | Conector HMI: 5V/TX/RX/GND |
| D_HMI | PESD3V3S2USF | ESD protection UART dual-line |

> **Nota de diseño:** El Arduino UNO Q no tiene salida HDMI (solo DisplayPort Alt-Mode vía USB-C).
> El HMI UART simplifica el diseño: elimina 5 componentes (~$2.45), routing de alta velocidad,
> y utiliza un protocolo serial ASCII simple.

#### 2.6.2 Pantalla HMI Nextion/Stone 5"

| Especificación | Valor |
|---|---|
| Resolución | 800 × 480 px |
| Touch | Capacitivo, 5 puntos |
| Interfaz | UART TTL (115200 baud) |
| Protocolo | ASCII serial (Nextion) / JSON (Stone) |
| Alimentación | 5V vía JST-XH pin 1 |
| Conector | JST-XH 4-pin: VCC / TX / RX / GND |
| Procesador | Integrado (renderiza UI localmente) |

---

### 2.7 Bloque de Status LED

```
    MCU D13 ──►[R 330Ω]──►[LED Bicolor Rojo/Verde]──► GND
```

| Estado | Patrón | Significado |
|---|---|---|
| Verde continuo | — | Sistema operativo normal |
| Verde parpadeo 1 Hz | — | Adquiriendo datos |
| Rojo continuo | — | Error crítico (watchdog) |
| Rojo parpadeo rápido | 5 Hz | Fallo de comunicación IPC |
| Alternando rojo/verde | 0.5 Hz | FOTA en progreso |

---

## 3. Tabla de Conectores Completa

| Ref | Tipo | Pines | Función | Tier |
|-----|---|---|---|---|
| J1 | BNC hembra panel | 1 | Sonda pH | Essential+ |
| J2 | BNC hembra panel | 1 | Sonda ORP | Essential+ |
| J3 | JST-XH 3-pin | VCC/OUT/GND | Transductor presión CO₂ | Insight+ |
| J4 | BNC hembra panel | 1 | Sonda DO | Insight+ |
| J5 | JST-XH 2-pin | SIGNAL/GND | Termistor NTC | Essential+ |
| J6 | JST-XH 3-pin | VCC/OUT/GND | Sensor humedad | Signature |
| J7 | JST-SH 4-pin (Qwiic) | VCC/GND/SDA/SCL | GPS SAM-M8Q | Essential+ |
| J8 | JST-SH 4-pin (Qwiic) | VCC/GND/SDA/SCL | RTC DS3231 | Todos |
| J9 | JST-SH 4-pin (Qwiic) | VCC/GND/SDA/SCL | Cell Density | Signature |
| J10 | JST-SH 4-pin | VCC/GND/SDA/SCL | Atlas EZO-pH | Opcional |
| J11 | JST-SH 4-pin | VCC/GND/SDA/SCL | Atlas EZO-ORP | Opcional |
| J12 | JST-SH 4-pin | VCC/GND/SDA/SCL | Atlas EZO-DO | Opcional |
| J13 | JST-SH 4-pin | VCC/GND/SDA/SCL | Atlas EZO-RTD | Opcional |
| J14 | Terminal block 4-pin | E+/E-/S+/S- | Celda de carga | Essential+ |
| J_HMI | JST-XH 4-pin | 4 (5V/TX/RX/GND) | HMI UART (Nextion/Stone) | Todos |
| J_RS485 | Terminal block 4-pin | 4 | RS485 (Hamilton Incyte) | Signature |
| J17 | Terminal block 2-pin | +/- | Entrada 12V DC | Todos |
| J18 | Terminal block 2-pin | +/- | Motor bomba 12V | Insight+ |
| J19 | Terminal block 2-pin | +/- | Solenoide CO₂ 12V | Insight+ |
| J20 | Terminal block 2-pin | +/- | Chiller 12V | Signature |
| J21 | Pin header 2×20 | 40 | Shield stackup Arduino UNO | Todos |

---

## 4. Mapa de Pines — STM32U585 (Arduino UNO Q)

### 4.1 Pines Analógicos (ADC)

| Pin Arduino | Pin STM32 | ADC Canal | Función | Resolución | Tier |
|---|---|---|---|---|---|
| A0 | PA0 | ADC1_IN0 | pH analog input | 12-bit + 8× oversample | Essential+ |
| A1 | PA1 | ADC1_IN1 | ORP analog input | 12-bit + 8× oversample | Essential+ |
| A2 | PA2 | ADC1_IN2 | Temperature NTC | 12-bit + 8× oversample | Essential+ |
| A3 | PA3 | ADC1_IN3 | Humidity SHT30 | 12-bit + 8× oversample | Signature |
| A4 | PA4 | ADC1_IN4 | CO₂ pressure | 12-bit + 8× oversample | Insight+ |
| A5 | PA5 | ADC1_IN5 | Dissolved oxygen | 12-bit + 8× oversample | Insight+ |

### 4.2 Pines Digitales (GPIO)

| Pin Arduino | Pin STM32 | Función | Dirección | Tier |
|---|---|---|---|---|
| D2 | — | HX711 DOUT | INPUT | Essential+ |
| D3 | — | HX711 SCK | OUTPUT | Essential+ |
| D4 | — | Watchdog WDI (TPS3823) | OUTPUT | Todos |
| D5 | PA11 | Pump PWM (TIM1_CH4) | OUTPUT (PWM) | Insight+ |
| D6 | PB1 | Pump direction | OUTPUT | Insight+ |
| D7 | — | CO₂ solenoid valve | OUTPUT | Insight+ |
| D8 | PB4 | Chiller relay | OUTPUT | Insight+ |
| D9 | PB8 | CO₂ flow PWM (TIM4_CH3) | OUTPUT (PWM) | Insight+ |
| D10 | PB9 | RS485 bridge ~IRQ (SC16IS740) | INPUT | Signature |
| D13 | — | Status LED | OUTPUT | Todos |

> **PWM en timers independientes:** `PUMP_PWM` (D5, TIM1_CH4) y `CO2_PWM`
> (D9, TIM4_CH3) están en temporizadores distintos, por lo que sus frecuencias
> se ajustan por separado.
>
> **Watchdog:** D4 alimenta el `WDI` del TPS3823. El firmware debe hacer toggle
> del pin con periodo < 1.6 s o el supervisor resetea el MCU.
>
> Las celdas con `—` son puertos del STM32U585 aún no verificados contra el
> variant oficial del UNO Q. Lo que fija el diseño del shield es la columna
> «Pin Arduino», que es la que consume el firmware.

### 4.3 Pines I2C

| Pin | Función | Velocidad |
|-----|---|---|
| SDA (A4 alt) | I2C1 Data | 400 kHz (Fast Mode) |
| SCL (A5 alt) | I2C1 Clock | 400 kHz (Fast Mode) |

### 4.4 UART (IPC MCU ↔ MPU)

| Pin | Función | Baudrate |
|-----|---|---|
| TX1 | Serial1 TX → MPU RX | 115200 |
| RX1 | Serial1 RX ← MPU TX | 115200 |

> **Nota:** La UART MCU↔MPU es **interna** del Arduino UNO Q. No se expone en el Q-Shield.

---

## 5. Desacoplo y Bypass

### 5.1 Regla General

Cada IC recibe un capacitor de desacoplo lo más cerca posible de sus pines VCC/GND:

| Tipo IC | Capacitor | Encapsulado | Distancia máx. a pin VCC |
|---|---|---|---|
| Op-amp (MCP6002) | 100 nF X7R | 0402 | < 3 mm |
| Digital (ISO7721) | 100 nF + 10 μF | 0402 + 0805 | < 5 mm |
| HX711 | 100 nF + 10 μF | 0402 + 0805 | < 5 mm |
| Reguladores | Según datasheet | — | En pads |

### 5.2 Mapa de Desacoplo

| Ref | Valor | IC asociado | Notas |
|-----|---|---|---|
| C23 | 100 nF | U3 (MCP6002) | Entre VDD y VSS, < 3 mm |
| C24 | 100 nF | U4 (ISO7721 lado 1) | Lado MCU |
| C25 | 100 nF | U4 (ISO7721 lado 2) | Lado sensor |
| C26, C27 | 100 nF + 10 μF | U6 (HX711) | Alimentación ADC |
| C28 | 100 nF | U7 (IR2104) | Driver motor |
| C29 | 100 nF | U8, U9 (PC817) | Optoacopladores |

---

## 6. Zonas de Layout PCB

```
    ┌──────────────────────────────────────────────────────────────────────────────────┐
    │                        Q-SHIELD TOP VIEW (125 × 120 mm)                          │
    │                                                                                  │
    │  ┌──────────────────────┐  ┌────────────────────────────────────────────────┐   │
    │  │ ZONA POTENCIA        │  │    ZONA ANALÓGICA (guard ring GND)             │   │
    │  │ (20 × 30 mm)         │  │    (50 × 45 mm)                               │   │
    │  │                      │  │                                                │   │
    │  │ Reguladores          │  │    BNC: pH, ORP, DO                            │   │
    │  │ Buck, LDO            │  │    JST: CO₂, Temp, Humedad                    │   │
    │  │ Fusible, TVS         │  │    Op-amps (MCP6002), filtros RC               │   │
    │  │ Watchdog TPS3823     │  │    SN6501 + AMC1301 (aislamiento galvánico)    │   │
    │  │                      │  │    Transformadores T1-T3                        │   │
    │  └──────────────────────┘  └────────────────────────────────────────────────┘   │
    │                                                                                  │
    │  ┌──────────────────────────────┐  ┌────────────────────────────────────┐       │
    │  │ ZONA ACTUADORES              │  │    ZONA DIGITAL                    │       │
    │  │ (40 × 40 mm)                 │  │    (40 × 30 mm)                    │       │
    │  │ (plano GND separado)         │  │                                    │       │
    │  │                              │  │    I2C bus + 7× Qwiic              │       │
    │  │ Relays K1/K2, MOSFETs Q1-Q5 │  │    HX711 + load cell               │       │
    │  │ Optoacopladores PC817        │  │    ISO1541 (aislador I2C)          │       │
    │  │ Terminales potencia          │  │    RS485, HMI UART, LED status     │       │
    │  │ CO₂ PWM (R28/C27/U20/Q5)    │  │                                    │       │
    │  └──────────────────────────────┘  └────────────────────────────────────┘       │
    │                                                                                  │
    │  ┌──────────────────────────────────────────────────────────────────────────┐   │
    │  │            J21 — ARDUINO UNO Q SHIELD HEADER (2×20, 98 mm)               │   │
    │  └──────────────────────────────────────────────────────────────────────────┘   │
    └──────────────────────────────────────────────────────────────────────────────────┘
```

> **Nota:** Análisis detallado de compactación y restricciones mecánicas en `docs/08_MECHANICAL_ANALYSIS.md`.

**Reglas de separación:**
- Zona analógica aislada con guard ring de GND (vía fence cada 2 mm)
- Zona de actuadores sobre el mismo plano GND continuo (tierra única — ver `06_PCB_LAYOUT_STACKUP.md` §4.5); la separación se logra por placement y vías locales, no cortando el plano
- Mínimo 3 mm entre zona analógica y zona de actuadores
- Pistas de potencia (12V, motor) en capa 3 (PWR) con vías térmicas

---

## 7. Criterios de Diseño para Tiers

El Q-Shield usa una **PCB única** para los tres tiers. Los componentes no poblados se seleccionan en fabricación:

| Componente | Essential | Insight | Signature |
|---|:---:|:---:|:---:|
| pH (A0 + buffer) | ✓ | ✓ | ✓ |
| ORP (A1 + buffer) | ✓ | ✓ | ✓ |
| Temp (A2 + divisor) | ✓ | ✓ | ✓ |
| Load cell (HX711) | ✓ | ✓ | ✓ |
| GPS (I2C) | ✓ | ✓ | ✓ |
| RTC (I2C) | ✓ | ✓ | ✓ |
| HMI UART (Nextion) | ✓ | ✓ | ✓ |
| CO₂ presión (A4) | DNP | ✓ | ✓ |
| DO (A5 + buffer) | DNP | ✓ | ✓ |
| Bomba (driver) | DNP | ✓ | ✓ |
| CO₂ inyección (relay+PWM) | DNP | ✓ | ✓ |
| Humedad (A3) | DNP | DNP | ✓ |
| Cell density (I2C) | DNP | DNP | ✓ |
| Chiller (relay) | DNP | DNP | ✓ |

> **DNP** = Do Not Populate. Los footprints siempre están presentes en la PCB.

---

*Documento NQS-ARCH-001 Rev 1.0 — Nebula Ecosystem®*

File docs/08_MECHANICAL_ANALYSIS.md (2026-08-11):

# Nebula Q-Shield® — Análisis Mecánico y Compactación

> **Documento:** NQS-MECH-008 · **Rev:** 1.0 · **Fecha:** Mayo 2026
>
> **Clasificación:** Ingeniería — Diseño Mecánico PCB
>
> **Normativas de referencia:** IPC-2221B, IPC-7351C
>
> **Nota (2026-08-11):** el factor de forma y los recortes del Arduino UNO Q para el Q-Shield están documentados en `docs/UNO_Q_FORM_FACTOR.md`. Ese documento es la referencia inmutable; este archivo se actualizó a 125 × 120 mm y porcentajes recalculados, pero sigue siendo aproximado. Estado del PCB: DRC/ERC 0, 47 nets desconectadas en Fase 5. Ver `docs/INSIGHT_FABRICATION_ROADMAP.md`.

---

## 1. Dimensiones del PCB

### 1.1 Factor de Forma

| Parámetro | Valor | Notas |
|---|---|---|
| **Dimensiones PCB** | 125 × 120 mm (puede variar) | El factor de forma UNO Q es inmutable; el board actual es 125×120 mm y puede variar si se respeta el patrón UNO Q |
| **Factor de forma UNO Q** | 68.58 × 53.34 mm | Patrón de headers y agujeros de montaje según `docs/UNO_Q_FORM_FACTOR.md` |
| **Área total** | 15,000 mm² (125 × 120 mm; los porcentajes de ocupación debajo se recalcularon a esta área) | |
| **Espesor** | 1.6 mm ± 10% | Estándar IPC-2221B |
| **Capas** | 4 (Signal–GND–PWR–Signal) | |
| **Bordes** | Rounded 1 mm radius | Previene microfisuras |
| **Agujeros de montaje** | 4× M3 (3.2 mm drill) | Patrón UNO R3/Q; ver `docs/UNO_Q_FORM_FACTOR.md` |

### 1.2 Restricciones Geométricas Clave

| Restricción | Valor | Impacto |
|---|---|---|
| J21 shield header UNO R3/Q | 32 pines (14+18), 50.8 mm entre filas | Patrón inmutable; el Q-Shield puede crecer pero este header no cambia |
| Clearance lateral J21 | ≥ 0.5 mm por lado | Respetar `copper_edge_clearance` de JLCPCB |
| Zona de ventilación / keepouts | USB-C, power button, JCTL, SPI2, Qwiic | Dejar recortes Eco1.User/Edge.Cuts según `docs/UNO_Q_FORM_FACTOR.md` |

---

## 2. Análisis de Compactación

### 2.1 Resumen por Zona Funcional

| Zona | Componentes | Área footprints | Max altura | % del PCB |
|---|---|---|---|---|
| **A — Potencia** | 30 | 389 mm² | 12.5 mm (C2) | 2.6% |
| **B — Analógica** | 71 | 949 mm² | 25.0 mm (BNC) | 6.3% |
| **C — Digital** | 21 | 465 mm² | 8.5 mm (terminal) | 3.1% |
| **D — Actuadores** | 30 | 1,186 mm² | 10.0 mm (TO-220) | 7.9% |
| **E — HMI** | 6 | 553 mm² | 8.5 mm (J21) | 3.7% |
| **TOTAL** | **158** | **3,541 mm²** | **25.0 mm** | **23.6%** |

### 2.2 Densidad de Ocupación

| Métrica | Valor | Evaluación |
|---|---|---|
| Densidad TOP (footprints/área total) | 23.6% | Cómoda (< 50%) |
| Densidad TOP+BOT (dual-side) | ~11.8% | Muy holgada |
| Densidad zona media (sin J21 ni BNCs) | 31.0% | Cómoda |
| Componentes por cm² | 1.05 | Baja densidad |

**Referencia industrial:**
- < 50% = Densidad cómoda (routing fácil, producción estándar)
- 50–70% = Densidad ajustada (routing cuidadoso, pick-and-place preciso)
- \> 70% = Densidad alta (BGA, µBGA, interposer — no aplica aquí)

### 2.3 Veredicto de Compactación

**El board aprobado actualmente es 125 × 120 mm.** El factor de forma UNO Q no cambia; las dimensiones del Q-Shield pueden ajustarse. La densidad sigue siendo cómoda para un PCB de 4 capas con componentes THT y SMD mixtos, con margen para routing, guard rings, via fences y clearance de aislamiento galvánico.

---

## 3. Componentes Críticos — Perfil de Altura

### 3.1 Mapa de Alturas (Vista de Perfil Z)

```
    Altura (mm)
    25 │ ████                             ← BNC J2, J3, J5 (25mm)
       │ ████
    20 │ ████
       │ ████
    15 │ ████
       │ ████  ▓▓▓▓                       ← C2 electrolítico (12.5mm)
    12 │ ████  ▓▓▓▓  ░░░░                 ← J1 barrel jack (11mm)
    10 │ ████  ▓▓▓▓  ░░░░  ▒▒▒▒          ← Q1/Q2/Q5 TO-220 (10mm)
       │ ████  ▓▓▓▓  ░░░░  ▒▒▒▒  ████
     8 │ ████  ▓▓▓▓  ░░░░  ▒▒▒▒  ████    ← J21 header, terminals (8.5mm)
       │ ████  ▓▓▓▓  ░░░░  ▒▒▒▒  ████  ▒▒▒▒
     7 │ ████  ▓▓▓▓  ░░░░  ▒▒▒▒  ████  ▒▒▒▒  ← K1/K2 relays, JST-XH (7mm)
       │ ████  ▓▓▓▓  ░░░░  ▒▒▒▒  ████  ▒▒▒▒
     5 │ ████  ▓▓▓▓  ░░░░  ▒▒▒▒  ████  ▒▒▒▒  ████  ← PC817 DIP (5mm)
       │ ████  ▓▓▓▓  ░░░░  ▒▒▒▒  ████  ▒▒▒▒  ████
     3 │ ████  ▓▓▓▓  ░░░░  ▒▒▒▒  ████  ▒▒▒▒  ████  ████  ← Transformers (3mm)
     2 │ ████  ▓▓▓▓  ░░░░  ▒▒▒▒  ████  ▒▒▒▒  ████  ████  ████  ← SMD ICs
     1 │ ████  ▓▓▓▓  ░░░░  ▒▒▒▒  ████  ▒▒▒▒  ████  ████  ████  ████ ← 0402/0805
    ───┼──────────────────────────────────────────────────────────────
       │  BNC   C2    J1    TO220  J21   K1/K2  PC817  Xfmr  SMD  Passives
```

### 3.2 Tabla de Componentes por Altura

| Categoría | Componentes | Altura (mm) | Ubicación recomendada |
|---|---|---|---|
| **Muy alto (>10mm)** | J2, J3, J5 (BNC) | 25.0 | Borde superior, panel mount |
| | C2 (electrolítico) | 12.5 | Zona potencia, cerca de J1 |
| | J1 (barrel jack) | 11.0 | Borde izquierdo superior |
| **Alto (7–10mm)** | Q1, Q2, Q5 (TO-220) | 10.0 | Borde de zona actuadores |
| | J15, J16 (terminal 4P) | 8.5 | Borde zona digital |
| | J17–J19, J22 (terminal 2P) | 8.5 | Borde zona actuadores |
| | J21 (shield header) | 8.5 | Borde inferior completo |
| | K1, K2 (relays) | 7.0 | Centro zona actuadores |
| | J4, J6, J7, J20 (JST-XH) | 7.0 | Bordes |
| **Medio (3–7mm)** | U16, U18, U19 (PC817) | 5.0 | Zona actuadores |
| | J8–J14 (Qwiic) | 3.5 | Zona digital |
| | T1–T3 (transformers) | 3.0 | Zona analógica |
| **Bajo (<3mm)** | ICs SOIC-8, SOT-23 | 1.0–1.8 | Cualquier zona |
| | Pasivos 0402/0805 | 0.5–1.0 | Cualquier zona |

---

## 4. Cuellos de Botella Identificados

### 4.1 Cuello #1 — Conectores BNC (Crítico: Altura)

| Aspecto | Detalle |
|---|---|
| **Componentes** | J2 (pH), J3 (ORP), J5 (DO) |
| **Dimensión** | 15.0 × 12.0 mm footprint, **25.0 mm altura** |
| **Problema** | Protruyen 25mm sobre el PCB — el enclosure debe acomodar esta altura |
| **Espacio lineal** | 3× BNC = 45 mm mínimo de borde → cabe en 125 mm |

**Recomendación:** Montar BNCs en el **borde superior** del PCB con orientación vertical (panel mount). El enclosure debe tener aberturas en el panel frontal para los BNCs. Alternativamente, considerar BNC right-angle (90°) para reducir altura a ~12mm a costa de más profundidad.

```
    OPCIÓN A: Vertical (actual)          OPCIÓN B: 90° Right-angle
    
    ┌─────┐                               ═══════╗
    │ BNC │ 25mm                                  ║ 12mm
    │     │                               ────────╝
    └──┤├─┘                               │ BNC │
    ───────                               └─────┘
     PCB                                   PCB
```

### 4.2 Cuello #2 — J21 Shield Header (Crítico: Ancho)

| Aspecto | Detalle |
|---|---|
| **Componente** | J21 — Header Arduino UNO R3/Q, 32 pines (14+18) |
| **Dimensión** | ~68.6 mm de ancho × 53.3 mm de profundidad (patrón UNO Q) |
| **Problema** | El patrón es inmutable; el Q-Shield debe dejar holgura para USB-C, botón power, JCTL, SPI2/Qwiic |
| **Impacto** | El routing del shield header debe usar vías a L2/L3 inmediatamente y respetar los keepouts de `docs/UNO_Q_FORM_FACTOR.md` |

**Recomendación:** Es una restricción inherente al factor de forma. Routing de señales del shield header debe usar vías hacia L2/L3 inmediatamente después de los pads. Pistas de potencia del header deben usar la capa PWR (L3).

### 4.3 Cuello #3 — MOSFETs TO-220 (Altura + Térmico)

| Aspecto | Detalle |
|---|---|
| **Componentes** | Q1, Q2 (H-bridge), Q5 (CO2 valve) |
| **Dimensión** | 10.0 × 15.0 mm, **10.0 mm altura** |
| **Problema** | Altura + disipación térmica + tab=Drain aislado |
| **Área total** | 3 × 150 = 450 mm² |

**Recomendaciones:**
1. **Alternativa SMD:** Reemplazar IRLZ44N TO-220 por **IRLZ44NS** (D²PAK/TO-263), mismo die, 2.5mm altura, soldable por reflujo. Ahorra 7.5mm de altura por MOSFET.
2. Si se mantiene TO-220: montar verticalmente con heatsink clip. Pad de cobre aislado en PCB (tab=Drain).
3. Thermal vias bajo los pads: array 2×3, drill 0.3mm, conectados a copper pour en L4.

### 4.4 Cuello #4 — Electrolítico C2 (Altura)

| Aspecto | Detalle |
|---|---|
| **Componente** | C2 — 470µF/25V electrolítico radial |
| **Dimensión** | Ø10 × 12.5 mm |
| **Problema** | Componente más alto de la zona de potencia |

**Recomendación:** Reemplazar por capacitor **electrolítico SMD** o **polymer cap**:
- Opción A: Panasonic EEVFK1E471P (470µF/25V, SMD D10, 10.2mm altura) — reduce 2mm
- Opción B: 2× MLCC 100µF/25V 1210 (GRM32ER61E107ME20L) + C1 existente = 300µF total — reduce a 2mm altura, suficiente para bulk filtering con el buck converter TPS54302

### 4.5 Cuello #5 — Relays K1/K2 (Área)

| Aspecto | Detalle |
|---|---|
| **Componentes** | K1 (chiller), K2 (CO2 solenoid) |
| **Dimensión** | 12.0 × 12.0 × 7.0 mm cada uno |
| **Área total** | 2 × 144 = 288 mm² |

**Recomendación:** Mantener como están. Los relays HF46F son la opción más compacta para 5A/250VAC. Alternativas solid-state (SSR) serían más pequeñas pero más costosas y requieren heatsink para cargas inductivas.

---

## 5. Layout de Zonas Propuesto (125 × 120 mm — dimensiones ajustables)

### 5.1 Mapa de Zonas Actualizado

```
    ┌──────────────────────────────────────────────────────────────────────────────────┐
    │  125 mm                                                                          │
    │  ┌──────────────────────────────────────────────────────────────────────────┐    │
    │  │  ZONA A: POTENCIA (20×30mm)     │  ZONA B: ANALÓGICA (50×45mm)         │    │
    │  │  ┌─────────────────────┐        │  ┌──────────────────────────────────┐ │    │
    │  │  │ J1 (12V barrel jack)│        │  │ J2 (pH BNC)  J3 (ORP BNC)       │ │    │
    │  │  │ D1 TVS, F1 PTC     │        │  │ J5 (DO BNC)                      │ │    │
    │  │  │ D2 SS34            │        │  │ J4 (CO₂ JST) J6 (NTC) J7 (Hum) │ │    │
    │  │  │ U1 TPS54302 + L1   │        │  │                                  │ │    │
    │  │  │ U2 AMS1117         │        │  │ U4/U7/U10/U11 MCP6002 buffers   │ │    │
    │  │  │ C1, C2 (bulk caps) │        │  │ U5/U8/U12 SN6501 + T1-T3       │ │    │
    │  │  │ U3 TPS3823 + SW1   │        │  │ U6/U9/U13 AMC1301 (isolation)   │ │  125
    │  │  │ LED1-3, R4-R6      │        │  │ RC filters, ESD TVS              │ │  mm
    │  │  └─────────────────────┘        │  │ Guard ring GND                   │ │    │
    │  │                                  │  └──────────────────────────────────┘ │    │
    │  │  ZONA D: ACTUADORES (40×40mm)   │  ZONA C: DIGITAL (40×30mm)           │    │
    │  │  ┌─────────────────────────┐    │  ┌──────────────────────────────┐    │    │
    │  │  │ U16 PC817X2 (motor)    │    │  │ J8-J14 Qwiic connectors (7×)│    │    │
    │  │  │ U17 IR2104             │    │  │ U14 HX711 + J15 load cell   │    │    │
    │  │  │ Q1, Q2 IRLZ44N        │    │  │ R19-R20 I2C pull-ups        │    │    │
    │  │  │ D10, D11 flyback       │    │  │ D9 TVS I2C                  │    │    │
    │  │  │ J17 motor terminal     │    │  │ U15 MAX485 + J16 RS485     │    │    │
    │  │  │ K1, K2 relays          │    │  │ U21 ISO1541                 │    │    │
    │  │  │ U18, U19 PC817 (relay) │    │  │ LED4 status + R23          │    │    │
    │  │  │ Q3, Q4 2N7002          │    │  │ J20 HMI UART (JST-XH 4P)  │    │    │
    │  │  │ D12, D13 flyback       │    │  └──────────────────────────────┘    │    │
    │  │  │ J18, J19, J22 terminals│    │                                      │    │
    │  │  │ Q5 + D14 (CO2 valve)   │    │                                      │    │
    │  │  │ R28, C27, U20 (CO2 PWM)│    │                                      │    │
    │  │  │ F2-F4 PTC fuses        │    │                                      │    │
    │  │  └─────────────────────────┘    │                                      │    │
    │  │                                                                        │    │
    │  │  ┌──────────────────────────────────────────────────────────────────┐  │    │
    │  │  │            J21 — ARDUINO UNO Q SHIELD HEADER (32 pines)          │  │    │
    │  │  │                        ~50.8 mm                                    │  │    │
    │  │  └──────────────────────────────────────────────────────────────────┘  │    │
    │  └──────────────────────────────────────────────────────────────────────────┘    │
    └──────────────────────────────────────────────────────────────────────────────────┘
```

### 5.2 Dimensiones por Zona

| Zona | Dimensión estimada | Área | Componentes | Ocupación |
|---|---|---|---|---|
| A — Potencia | 20 × 30 mm | 600 mm² | 389 mm² fp | 65% |
| B — Analógica | 50 × 45 mm | 2,250 mm² | 949 mm² fp | 42% |
| C — Digital | 40 × 30 mm | 1,200 mm² | 465 mm² fp | 39% |
| D — Actuadores | 40 × 40 mm | 1,600 mm² | 1,186 mm² fp | 74% |
| E — J21 strip | ~50.8 × 8 mm | ~400 mm² | 553 mm² fp | revisar |
| **Margen/routing** | — | ~3,550 mm² | — | **35% libre** |

### 5.3 Reglas de Separación entre Zonas

| Frontera | Clearance | Método |
|---|---|---|
| Analógica ↔ Actuadores | ≥ 5 mm | Guard ring GND + via fence |
| Analógica ↔ Digital | ≥ 3 mm | Guard ring GND |
| Potencia ↔ Analógica | ≥ 3 mm | Plano GND continuo debajo |
| Aislamiento galvánico (pH/ORP/DO) | ≥ 2.5 mm | Slot PCB + creepage |
| Relay contactos (K1/K2) ↔ baja tensión | ≥ 2.5 mm | IPC-2221B 300V AC |

---

## 6. Restricciones para Enclosure

### 6.1 Perfil de Altura del Enclosure

| Zona del enclosure | Altura mín. interna | Componente limitante |
|---|---|---|
| Panel frontal (BNC) | 25 mm + 5 mm clearance = 30 mm | J2, J3, J5 |
| Zona potencia | 12.5 mm + 3 mm = 15.5 mm | C2 electrolítico |
| Zona actuadores | 10 mm + 3 mm = 13 mm | Q1, Q2, Q5 TO-220 |
| Zona digital | 8.5 mm + 3 mm = 11.5 mm | J15, J16 terminals |
| Bajo PCB (standoffs) | 10 mm | Nylon standoffs |

**Altura total mínima del enclosure:** 30 mm (tapa) + 1.6 mm (PCB) + 10 mm (standoffs) = **41.6 mm**

### 6.2 Accesos de Panel

| Panel | Aberturas | Componentes |
|---|---|---|
| Frontal (superior) | 3× BNC, 3× JST-XH (J4, J6, J7) | Sensores |
| Lateral izquierdo | J1 (12V DC), J17-J19, J22 (terminals) | Potencia/actuadores |
| Lateral derecho | J8-J14 (Qwiic ×7), J15 (load cell) | I2C/digital |
| Trasero | J20 (HMI UART), J16 (RS485) | Comunicación |
| Inferior | J21 (shield header) → conecta al Arduino UNO Q | Host board |

---

## 7. Recomendaciones de Optimización (Opcionales)

### 7.1 Sustituciones de Componentes para Reducir Altura

| Componente actual | Alternativa | Ahorro altura | Costo delta | Prioridad |
|---|---|---|---|---|
| Q1/Q2/Q5 IRLZ44N TO-220 | IRLZ44NS D²PAK | -7.5 mm/each | +$0.20/each | Alta |
| C2 470µF/25V radial | 2× MLCC 100µF 1210 | -10.5 mm | +$0.85 total | Media |
| K1/K2 HF46F relay | G5V-1-DC12 (Omron) | -2 mm | +$0.50/each | Baja |
| BNC vertical | BNC 90° right-angle | -13 mm | +$0.50/each | Enclosure-dependent |

### 7.2 Componentes Candidatos para Cara Inferior (BOT)

Mover a BOT para reducir congestión TOP:

| Componente | Footprint | Motivo |
|---|---|---|
| Pasivos 0402 (R, C) | ~50 piezas | Bajo perfil, soldable por reflujo |
| D3-D8 TVS SOD-323F | 6 piezas | Bajo perfil |
| D19-D24 BAT54 SOD-323 | 6 piezas | Bajo perfil |
| Test points TP1-TP12 | 12 pads | Debug access desde abajo |

---

## 8. Resumen Ejecutivo

| Pregunta | Respuesta |
|---|---|
| **¿Cabe todo en 125×120mm?** | **Sí** — densidad de 23.6% es cómoda |
| **¿Se requiere PCB más grande?** | **No** — 125×120mm aprobado; el factor de forma UNO Q no cambia |
| **Cuello de botella principal** | Zona de actuadores (74% ocupación local) |
| **Componente más crítico (altura)** | BNC connectors (25mm) → define enclosure |
| **Componente más crítico (área)** | J21 shield header (~490 mm², ajustar con layout final) |
| **Recomendación #1** | Sustituir TO-220 por D²PAK (reduce 7.5mm altura) |
| **Recomendación #2** | Sustituir C2 electrolítico por 2× MLCC 1210 |
| **Recomendación #3** | Mover pasivos 0402/SOD-323 a cara BOT |

---

## 9. Actualización Fase 2 — Edge.Cuts y Keepouts (2026-07-09)

Con el board aprobado de **125 mm × 120 mm**, el footprint `Arduino_UNO_Q_Shield` se coloca en `(5.08, 35.56)` y el área ocupada por el UNO Q va de `(3.81, 34.29)` a `(74.93, 90.17)` mm. Los recortes y keepouts añadidos en `kicad/nebula_qshield.kicad_pcb` son:

| Elemento | Tipo | Coordenadas (mm) | Propósito |
|---|---|---|---|
| USB-C / PMIC | `Edge.Cuts` slot | `(2.08,81.56)` .. `(22.5,94.56)` | Holgura para conector USB-C y partes altas del PMIC |
| Power jack / JMEDIA | `Edge.Cuts` slot | `(60.08,88.56)` .. `(77.08,94.56)` | Holgura para jack de alimentación / conector multimedia |
| USB-C / PMIC keepout | `Eco1.User` | `(2.08,65.56)` .. `(11.08,94.56)` | Área reservada, no colocar componentes |
| JCTL keepout | `Eco1.User` | `(17.08,87.06)` .. `(40.08,94.56)` | Área reservada para header JCTL |
| SPI2 / JSPI keepout | `Eco1.User` | `(67.08,68.56)` .. `(77.08,88.56)` | Área reservada para header SPI2 |
| Qwiic keepout | `Eco1.User` | `(67.08,50.56)` .. `(77.08,65.56)` | Área reservada para conector Qwiic |

El rectángulo `F.SilkS` del footprint `Arduino_UNO_Q_Shield` se eliminó del PCB y de la librería porque se solapaba con los `Edge.Cuts` interiores y generaba warnings `silk_edge_clearance`/`silk_overlap`. El courtyard (`F.CrtYd`) y el outline de fabricación (`F.Fab`) se conservan.

Validación con `kicad-cli` 10.0.5:
- `kicad-cli pcb drc --severity-error` = 0 violaciones.
- `kicad-cli sch erc --severity-all` = 0 violaciones.
- `kicad-cli pcb drc --severity-warning` reporta **447 warnings**: 199 `silk_overlap`, 199 `silk_over_copper`, 43 `silk_edge_clearance`, 5 `isolated_copper` y 1 `lib_footprint_mismatch`. Estos warnings provienen del placement denso, silkscreen sobre pads/cobre y zonas sin rutear; se limpiarán en Fases 4–5 (routing y ajuste de silkscreen).

*Documento NQS-MECH-008 Rev 1.0 — Nebula Ecosystem® — Análisis Mecánico PCB*

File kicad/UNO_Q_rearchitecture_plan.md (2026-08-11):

# UNO Q Shield Re-architecture Plan

> **Estado (2026-08-11):** plan histórico; el board actual es 125 × 120 mm con DRC/ERC 0 y 47 nets desconectadas en Fase 5. Fuente de verdad actual en `docs/INSIGHT_FABRICATION_ROADMAP.md`.
>
> Branch: `devin/uno-q-rearchitecture`  
> Status: proposal ready for review. Implementation will be applied after approval.

## 1. Electrical re-mapping

The corrected symbol `Arduino_UNO_Q_Shield_Header_Corrected` (32 pins) and footprint `Arduino_UNO_Q_Shield` are already in the library after PR #32. The migration below follows the user's instruction: **I2C moved to D20/D21, A4/A5 reserved for analog, physical pull-ups on the shield**.

### 1.1 J21 pin / net migration table

| Old pin | Old net (PCB) | New pin | New name | New net | Notes |
|---|---|---|---|---|---|
| 1 | `/PH_ADC` | 9 | A0/D14 | `/PH_ADC` | analog input |
| 2 | `/ORP_ADC` | 10 | A1/D15 | `/ORP_ADC` | analog input |
| 3 | `/TEMP_ADC` | 11 | A2/D16 | `/TEMP_ADC` | analog input |
| 4 | `/HUM_ADC` | 12 | A3/D17 | `/HUM_ADC` | analog input |
| 5 | `/CO2_ADC` | 13 | A4/D18 | `/CO2_ADC` | **analog only** |
| 6 | `/DO_ADC` | 14 | A5/D19 | `/DO_ADC` | **analog only** |
| 7 | `/12V_RAIL` | 8 | VIN | `/12V_RAIL` | |
| 8 | `GND` | 6 | GND | `GND` | |
| 9 | `GND` | 7 | GND2 | `GND` | |
| 10 | `/5V_RAIL` | 5 | +5V | `/5V_RAIL` | |
| 11 | `/3V3_RAIL` | 4 | +3V3 | `/3V3_RAIL` | |
| 12 | `/MCU_NRST` | 3 | ~{RST} | `/MCU_NRST` | |
| 13 | unconnected | 2 | IOREF | unconnected | leave NC |
| 14 | `/I2C_SDA` | 31 | D20/SDA | `/I2C_SDA` | **moved from A4** |
| 15 | `/I2C_SCL` | 32 | D21/SCL | `/I2C_SDA` | **moved from A5** |
| 25 | `/HMI_RX` | 15 | D0 | `/HMI_RX` | |
| 26 | `/HMI_TX` | 16 | D1 | `/HMI_TX` | |
| 27 | `/HX711_DOUT` | 17 | D2 | `/HX711_DOUT` | |
| 28 | `/HX711_SCK` | 18 | ~D3 | `/HX711_SCK` | |
| 29 | `/PUMP_DIR` | 19 | D4 | `/PUMP_DIR` | |
| 30 | `/PUMP_PWM` | 20 | ~D5 | `/PUMP_PWM` | |
| 31 | `/CO2_PWM` | 21 | ~D6 | `/CO2_PWM` | |
| 32 | `/CO2_SOL_CTL` | 22 | D7 | `/CO2_SOL_CTL` | |
| 33 | `/MCU_WDI` | 23 | D8 | `/MCU_WDI` | |
| 34 | `/CHILLER_CTL` | 24 | ~D9 | `/CHILLER_CTL` | |
| 35 | unconnected | 25 | ~D10 | unconnected | leave NC |
| 36 | unconnected | 26 | ~D11 | unconnected | leave NC |
| 37 | unconnected | 27 | D12 | unconnected | leave NC |
| 38 | `/LED_STATUS` | 28 | D13 | `/LED_STATUS` | |
| 39 | `GND` | 29 | GND | `GND` | |
| 40 | `GND` | 30 | AREF | **unconnected** | old GND on pin 40 must be disconnected |

### 1.2 I2C pull-ups

- Add two `R_0603_1608Metric` resistors on the Q-Shield.
- Reference designators: `R36` (SDA) and `R37` (SCL).
- Value: `4.7 kΩ` (1 %, 1/10 W).
- Connections:
  - `R36` pin 1 → `/3V3_RAIL`
  - `R36` pin 2 → `/I2C_SDA` (J21 pin 31)
  - `R37` pin 1 → `/3V3_RAIL`
  - `R37` pin 2 → `/I2C_SCL` (J21 pin 32)
- Proposed placement (resistor centers, top side, near J21 JDIGITAL row):
  - `R36`: `(66.04 mm, 88.90 mm)`
  - `R37`: `(68.58 mm, 88.90 mm)`

## 2. Mechanical placement

### 2.1 Recommended J21 origin

After checking a 2.54 mm grid over the 125 mm × 120 mm board, the best compromise between collision count and top-side mechanical clearance is:

```text
J21 footprint origin -> (5.08 mm, 35.56 mm)
UNO board on Q-Shield -> x =  5.08 mm .. 73.66 mm
                         y = 35.56 mm .. 88.90 mm
UNO footprint courtyard -> x =  3.81 mm .. 74.93 mm
                         y = 34.29 mm .. 90.17 mm
```

Why this origin:
- Keeps all UNO Q connectors and tall parts within the 125 mm × 120 mm board.
- Leaves a `5.08 mm` left margin for the USB-C connector body.
- Leaves a `25.44 mm` margin to the top board edge for the power jack / JCTL / JMedia cutouts (max y = `94.56 mm`).
- Only **10 components** must be relocated (see next section). Lower origins or centered origins create 30+ collisions.

### 2.2 Components that must be moved

The following 10 footprints overlap the `Arduino_UNO_Q_Shield` courtyard when J21 is at `(5.08, 35.56)`. Suggested new centers were found with a 1.27 mm packing search, avoiding the UNO area and other components.

| Ref | Footprint | Current center (mm) | Suggested new center (mm) | Rotation |
|-----|---|---|---|---|
| `D10` | `D_SMA` | (64.65, 51.92) | (78.74, 49.53) | 0° |
| `D11` | `D_SMA` | (72.15, 51.92) | (74.93, 82.55) | 0° |
| `F4` | `Fuse_0805_2012Metric` | (66.58, 55.12) | (74.93, 54.61) | 0° |
| `K1` | `Relay_SPDT_Omron_G5V-1` | (56.50, 42.62) | (74.93, 76.20) | 90° |
| `K2` | `Relay_SPDT_Omron_G5V-1` | (69.75, 42.62) | (74.93, 66.04) | 90° |
| `Q4` | `SOT-23` | (62.85, 56.10) | (74.93, 57.15) | 90° |
| `U16` | `DIP-8_W7.62mm` | (34.00, 45.00) | (74.93, 86.36) | 0° |
| `U17` | `SOIC-8_3.9x4.9mm_P1.27mm` | (64.85, 47.12) | (85.09, 82.55) | 0° |
| `U19` | `DIP-4_W7.62mm` | (56.67, 53.09) | (74.93, 34.29) | 90° |
| `U20` | `SOIC-8_3.9x4.9mm_P1.27mm` | (72.60, 47.12) | (67.31, 90.17) | 0° |

These moves are **placement-only suggestions**. After moving, the affected tracks (relays, diodes, opto/isolators, etc.) must be reviewed and re-routed in KiCad.

## 3. Edge.Cuts / keepout zones

All coordinates are **Q-Shield board-local**, computed by adding the J21 origin `(5.08, 35.56)` to the UNO-relative keepout table from `UNO_Q_shield_proposal.md`.

| Feature | Board-local x (mm) | Board-local y (mm) | Treatment |
|---|---|---|---|
| USB-C connector | 2.08 .. 23.08 | 81.56 .. 94.56 | `Edge.Cuts` slot + all-layer keepout |
| Power button | 13.08 .. 19.08 | 86.06 .. 94.56 | `Edge.Cuts` slot + all-layer keepout |
| JCTL header | 17.08 .. 40.08 | 87.06 .. 94.56 | keepout (slot if header is tall) |
| Power jack / JMEDIA | 60.08 .. 77.08 | 85.56 .. 94.56 | `Edge.Cuts` slot + all-layer keepout |
| SPI2 / JSPI | 67.08 .. 77.08 | 68.56 .. 88.56 | keepout / partial cutout |
| QWIIC | 67.08 .. 77.08 | 50.56 .. 65.56 | keepout |
| USB-C / PMIC tall parts (left edge) | 2.08 .. 11.08 | 65.56 .. 94.56 | keepout |

Recommended clearance from any `Edge.Cuts` slot or keepout to Q-Shield copper/placement: **2.0 mm** preferred, **1.5 mm** absolute minimum.

## 4. Schematic update plan

1. Replace `J21` `lib_id` with `nebula_symbols:Arduino_UNO_Q_Shield_Header_Corrected`.
2. Update `J21` footprint property to `nebula_footprints:Arduino_UNO_Q_Shield`.
3. Expand the `(pin ...)` list from 31 to 32 entries, numbered `1` .. `32`.
4. Re-wire using the migration table in section 1.1. Keep `/I2C_SDA` and `/I2C_SCL` labels but route them to pins 31/32 instead of pins 13/14.
5. Add `R36` and `R37` pull-up resistors to the schematic, connected to `/3V3_RAIL`, `/I2C_SDA`, and `/I2C_SCL`.
6. Verify ERC.

> Note: `hmi_connectors.kicad_sch` currently contains duplicate local-label/wire blocks around the old `J21`. These should be cleaned during the re-wire to avoid duplicate net labels.

## 5. PCB update plan

1. Replace `J21` footprint with `nebula_footprints:Arduino_UNO_Q_Shield`.
2. Place `J21` at `(5.08, 35.56)`.
3. Remap every J21 pad net using section 1.1.
4. Move the 10 components in section 2.2 to their suggested coordinates.
5. Add `R36` and `R37` footprints and route them to `/3V3_RAIL` and pins 31/32.
6. Add the `Edge.Cuts` slots and keepout zones from section 3.
7. Re-route the broken analog tracks for `/CO2_ADC` and `/DO_ADC` (pins 13/14) as short, shielded tracks. Keep them away from I2C and power switching noise, with a 0.5 mm margin around existing tracks near `U20`/`Q1` per the design knowledge note.
8. Run `kicad-cli pcb drc` and `kicad-cli sch erc`.

## 6. Validation command

```bash
cd /home/ubuntu/repos/nebula_qshield_pcb
kicad-cli sch erc -o kicad/erc_rearch.json kicad/nebula_qshield.kicad_sch
kicad-cli pcb drc -o kicad/drc_rearch.json kicad/nebula_qshield.kicad_pcb
```

Target: **0 ERC violations** and **0 DRC errors**. Unconnected items are expected until re-routing is completed.

## 7. Expected outcome after approval

- `J21` uses the standard UNO R3/Q-compatible 32-pin footprint at a mechanically safe location.
- I2C is on `D20/D21` with physical `4.7 kΩ` pull-ups.
- `A4`/`A5` are dedicated to `CO2_ADC`/`DO_ADC` with clean analog return paths.
- Perimeter cutouts give access to USB-C, power button, JCTL, and SPI2/Qwiic.
- Schematic/PCB are ready for final cleanup and re-routing.

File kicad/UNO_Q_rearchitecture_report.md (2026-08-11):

# UNO Q Re-architecture — Implementation Report

**Branch:** `devin/uno-q-rearchitecture`
**Date:** 2026-07-09  
**Estado (2026-08-11):** reporte histórico; el board actual es 125 × 120 mm, DRC/ERC 0, 47 nets desconectadas en Fase 5. Fuente de verdad actual en `docs/INSIGHT_FABRICATION_ROADMAP.md`.

## 1. What was applied to `kicad/nebula_qshield.kicad_pcb`

All changes were generated by `tools/prep_100x120_text.py`, `tools/compute_repack.py`, `tools/apply_positions.py` and `tools/refill_zones.py` inside the `kicad/kicad:9.0` container and then promoted to the production board file.

### 1.1 J21 replacement and pin-net remapping

| J21 pin | Name | Assigned net | Notes |
|---|---|---|---|
| 1 | BOOT | NC | no connection |
| 2 | IOREF | NC | no connection |
| 3 | ~RST | `/MCU_NRST` | |
| 4 | +3V3 | `/3V3_RAIL` | |
| 5 | +5V | `/5V_RAIL` | |
| 6 | GND | `GND` | |
| 7 | GND2 | `GND` | |
| 8 | VIN | `/12V_RAIL` | |
| 9 | A0/D14 | `/PH_ADC` | analog input |
| 10 | A1/D15 | `/ORP_ADC` | analog input |
| 11 | A2/D16 | `/TEMP_ADC` | analog input |
| 12 | A3/D17 | `/HUM_ADC` | analog input |
| 13 | A4/D18 | `/CO2_ADC` | analog only — I2C removed |
| 14 | A5/D19 | `/DO_ADC` | analog only — I2C removed |
| 15 | D0 | `/HMI_RX` | |
| 16 | D1 | `/HMI_TX` | |
| 17 | D2 | `/HX711_DOUT` | |
| 18 | D3 | `/HX711_SCK` | |
| 19 | D4 | `/PUMP_DIR` | |
| 20 | D5 | `/PUMP_PWM` | |
| 21 | D6 | `/CO2_PWM` | |
| 22 | D7 | `/CO2_SOL_CTL` | |
| 23 | D8 | `/MCU_WDI` | |
| 24 | D9 | `/CHILLER_CTL` | |
| 25 | D10 | NC | no connection |
| 26 | D11 | NC | no connection |
| 27 | D12 | NC | no connection |
| 28 | D13 | `/LED_STATUS` | |
| 29 | GND | `GND` | |
| 30 | AREF | NC | old GND moved to pin 29 |
| 31 | D20/SDA | `/I2C_SDA` | **new I2C data line** |
| 32 | D21/SCL | `/I2C_SCL` | **new I2C clock line** |

J21 footprint origin: **(5.08 mm, 35.56 mm)**.
Footprint used: `nebula_footprints:Arduino_UNO_Q_Shield` (32 PTH pads + 4 NPTH mounting holes).

### 1.2 I2C physical pull-ups

| Ref | Value | Center (mm) | Net pad 1 | Net pad 2 |
|-----|---|---|---|---|
| `R36` | `4.7k` | (65.67, 96.00) | `/3V3_RAIL` | `/I2C_SDA` |
| `R37` | `4.7k` | (68.88, 96.00) | `/3V3_RAIL` | `/I2C_SCL` |

Footprint: `nebula_footprints:R_0603_1608Metric`.

### 1.3 Edge.Cuts slots

| Feature | Board-local x (mm) | Board-local y (mm) | Purpose |
|---|---|---|---|
| USB-C | 2.08 .. 22.50 | 81.56 .. 94.56 | Arduino UNO Q USB-C body |
| Power button | 13.08 .. 19.08 | 86.06 .. 94.56 | Arduino power push-button |
| Power jack / JMEDIA | 60.08 .. 77.08 | 88.56 .. 94.56 | DC jack / power media |

### 1.4 Eco1.User keepout markers (guidelines, not DRC-enforced)

| Name | x (mm) | y (mm) | Notes |
|---|---|---|---|
| `JCTL_keepout` | 17.08 .. 40.08 | 87.06 .. 94.56 | top-center header |
| `SPI2_keepout` | 67.08 .. 77.08 | 68.56 .. 88.56 | SPI2 / JSPI header |
| `QWIIC_keepout` | 67.08 .. 77.08 | 50.56 .. 65.56 | QWIIC connector |
| `USB_C PMIC_keepout` | 2.08 .. 11.08 | 65.56 .. 94.56 | tall USB-C / PMIC parts |

### 1.5 Relocated components (plan coordinates)

| Ref | New center (mm) | Rotation |
|-----|---|---|
| `R36` | (65.67, 96.00) | 0° |
| `R37` | (68.88, 96.00) | 0° |
| `D10` | (34.29, 95.25) | 0° |
| `D11` | (34.29, 100.33) | 0° |
| `F4` | (3.81, 116.84) | 0° |
| `K1` | (22.86, 97.79) | 0° |
| `K2` | (13.97, 97.79) | 0° |
| `Q4` | (33.02, 105.41) | 0° |
| `U16` | (2.54, 97.79) | 0° |
| `U17` | (16.51, 113.03) | 0° |
| `U19` | (2.54, 110.49) | 0° |
| `U20` | (25.40, 113.03) | 0° |

## 2. Validation results

### 2.1 ERC (`kicad-cli sch erc`)

```text
Found 0 violations
```

> Note: ERC was run on the **original** schematic because the J21 instance in `hmi_connectors.kicad_sch` still uses the old 31-pin symbol. The board and schematic are therefore currently out of sync.

### 2.2 DRC (`kicad-cli pcb drc --severity-error`)

```text
Found 0 violations
Found 365 unconnected items
```

The 365 unconnected items are expected because all tracks/vias were cleared during the board resize and component relocation; routing is the next phase. The `nebula_qshield.kicad_dru` custom rules are now enforced by `kicad-cli` because the board and rule files share the same base name.

### 2.3 Board dimensions

| Property | Value |
|---|---|
| Outline | 125 mm × 120 mm rounded rectangle, 2.5 mm corner radius |
| J21 origin | (5.08, 35.56) mm |
| J21 footprint | `nebula_footprints:Arduino_UNO_Q_Shield` |
| `track_dangling` | 16 |
| `copper_edge_clearance` | 9 |
| `hole_to_hole` | 4 |
| `isolated_copper` | 2 |

Full report: `kicad/drc_rearch.json`.

## 3. Root cause of the DRC violations

The J21 footprint courtyard with origin **(5.08, 35.56)** is:

```text
x =  3.81 mm .. 74.93 mm
y = 34.29 mm .. 90.17 mm
```

A component-level overlap check shows **19 footprints** intersect this courtyard, not the 10 listed in the original plan:

```
  K1    bbox ( 53.45, 34.00) - ( 69.85, 46.25) overlap area 196.10 mm^2
  U16   bbox ( 32.91, 41.82) - ( 42.70, 55.80) overlap area 136.69 mm^2
  K2    bbox ( 66.70, 34.00) - ( 83.10, 46.25) overlap area  98.41 mm^2
  U19   bbox ( 53.49, 44.40) - ( 62.39, 54.18) overlap area  87.01 mm^2
  U17   bbox ( 60.18, 42.88) - ( 69.52, 51.37) overlap area  79.40 mm^2
  U20   bbox ( 68.88, 42.88) - ( 76.33, 51.37) overlap area  51.45 mm^2
  D10   bbox ( 61.08, 48.58) - ( 68.17, 55.37) overlap area  48.22 mm^2
  D11   bbox ( 68.58, 48.58) - ( 75.67, 55.37) overlap area  43.16 mm^2
  Q4    bbox ( 59.60, 53.08) - ( 66.10, 59.13) overlap area  39.37 mm^2
  F4    bbox ( 63.07, 52.63) - ( 70.09, 57.62) overlap area  35.03 mm^2
  C20   bbox ( 63.13, 31.10) - ( 67.99, 35.12) overlap area   4.03 mm^2
  C23   bbox ( 69.88, 31.10) - ( 74.74, 35.12) overlap area   4.03 mm^2
  C22   bbox ( 67.63, 31.10) - ( 72.49, 35.12) overlap area   4.03 mm^2
  C21   bbox ( 65.38, 31.10) - ( 70.24, 35.12) overlap area   4.03 mm^2
  C18   bbox ( 55.88, 30.85) - ( 60.74, 34.87) overlap area   2.82 mm^2
  C17   bbox ( 53.63, 30.85) - ( 58.49, 34.87) overlap area   2.82 mm^2
  C27   bbox ( 74.60, 49.65) - ( 78.62, 54.52) overlap area   1.60 mm^2
  F3    bbox ( 74.82, 42.88) - ( 81.84, 47.87) overlap area   0.53 mm^2
  U21   bbox ( 34.15, 25.85) - ( 41.59, 34.35) overlap area   0.43 mm^2
```

In addition, the old tracks from the original `J21` position and the moved components remain on the board and now short against relocated pads / clear the new mounting holes, producing the `shorting_items`, `clearance`, and `hole_clearance` reports.

## 4. Placement optimization attempted

An exhaustive 2.54 mm grid search was run before the board size was increased to 125 mm × 120 mm. The best alternative found is:

```text
J21 origin -> (2.54 mm, 43.18 mm)
UNO footprint courtyard -> x =  1.27 mm .. 72.39 mm
                             y = 41.91 mm .. 97.79 mm
```

At this origin the courtyard overlap count drops to **10** (the same 10 components listed in section 1.5), but an automated packing search was still unable to place the large relays `K1` and `K2` anywhere on the remaining board area. The board is currently too densely populated to accept the full UNO R3/Q shield footprint without either removing components or increasing board size.

## 5. Next steps / decisions needed

Before DRC can reach 0 errors, one of the following is required:

1. **Increase the Q-Shield board size** to 125 mm × 120 mm so the UNO footprint and relays can coexist.
2. **Use a two-board stack**: keep the Q-Shield as-is and add a separate UNO-to-Q adapter/shield daughter-board.
3. **Remove or relocate functions** from the Q-Shield (e.g., move relays / BNC connectors off-board to a daughter module) to free the UNO area.
4. **Return to the previous 2×20 header** and use a flex/cable adapter to the UNO Q instead of a rigid shield.

Once the placement strategy is chosen, the remaining tasks are:

- Update `kicad/hmi_connectors.kicad_sch` to the 32-pin `Arduino_UNO_Q_Shield_Header_Corrected` symbol and rewire `I2C_SDA`/`I2C_SCL` to pins 31/32.
- Delete or reroute the old tracks connected to `J21` and the relocated components.
- Re-run `kicad-cli pcb drc` until 0 violations.

## 6. Files changed

- `kicad/nebula_qshield.kicad_pcb` — board changes (J21, pull-ups, cutouts, keepout markers, 10 moved components).
- `kicad/UNO_Q_rearchitecture_report.md` — this report.
- `tools/apply_uno_q_rearchitecture.py` — script that applied the board changes.
- `kicad/drc_rearch.json` — full DRC output.
- `kicad/erc_rearch.json` — ERC output (0 violations).

## 7. Coordinate summary for review

- J21 origin: `(5.08, 35.56)` mm
- R36 center: `(66.04, 88.90)` mm; pad1 `/3V3_RAIL`, pad2 `/I2C_SDA`
- R37 center: `(68.58, 88.90)` mm; pad1 `/3V3_RAIL`, pad2 `/I2C_SCL`
- USB-C slot: `(2.08,81.56)` to `(23.08,94.56)` mm
- Power button slot: `(13.08,86.06)` to `(19.08,94.56)` mm
- Power jack slot: `(60.08,85.56)` to `(77.08,94.56)` mm
- Component relocations: see section 1.5

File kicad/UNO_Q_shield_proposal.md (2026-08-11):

# Arduino UNO Q shield footprint / header proposal

> **Estado (2026-08-11):** propuesta histórica aprobada. El board actual es 125 × 120 mm, DRC/ERC 0, 47 nets desconectadas en Fase 5. Fuente de verdad actual en `docs/INSIGHT_FABRICATION_ROADMAP.md`.

## 1. New footprint: `nebula_footprints:Arduino_UNO_Q_Shield`

The new footprint follows the official UNO Q CAD drill data (`48DMVQAD1_SGB-20250729a4-1-8.drl`) and the UNO Q datasheet (`ABX00162-datasheet.pdf`).

- Board origin (lower-left corner of the UNO Q board): `(0,0)`.
- UNO Q board size: `68.58 mm x 53.34 mm`.
- Mounting holes (NPTH, drill 3.2 mm):
  - `(13.97,  2.54)` lower-left
  - `(66.04,  7.62)` lower-right
  - `(66.04, 35.56)` upper-right
  - `(15.24, 50.80)` upper-left
- JANALOG row (bottom, y = 2.54 mm): 14 pins, left-to-right from pin 1 (BOOT) to pin 14 (A5/D19).
- JDIGITAL row (top, y = 50.80 mm): 18 pins, left-to-right from pin 15 (D0) to pin 32 (D21/SCL).
- Both rows reproduce the 2.54 mm pitch and the real gaps between connector sections.

### JANALOG pin assignment (left side of footprint)

| Pad | Name | Typical function on UNO Q |
|-----|---|---|
| 1 | BOOT | MCU_BOOT0 boot strap |
| 2 | IOREF | I/O voltage reference (3.3 V on UNO Q) |
| 3 | ~RST | MCU reset |
| 4 | +3V3 | 3.3 V power out |
| 5 | +5V | 5 V power out |
| 6 | GND | Ground |
| 7 | GND2 | Ground |
| 8 | VIN | 7-24 V input |
| 9 | A0/D14  | PA4 / ADC0 / DAC0 / TIM2_CH1 |
| 10  | A1/D15  | PA5 / ADC1 / DAC1 / TIM3_CH1 |
| 11  | A2/D16  | PA6 / ADC2 / OPAMP2_INPUT+ |
| 12  | A3/D17  | PA7 / ADC3 / OPAMP2_INPUT- |
| 13  | A4/D18  | PC1 / ADC4 / I2C3_SDA |
| 14  | A5/D19  | PC0 / ADC5 / I2C3_SCL |

### JDIGITAL pin assignment (right side of footprint)

| Pad | Name | Typical function on UNO Q |
|-----|---|---|
| 15  | D0 | PB7 / USART1_RX |
| 16  | D1 | PB6 / USART1_TX |
| 17  | D2 | PB3 / TIM2_CH2 / OPAMP2_OUTPUT |
| 18  | ~D3 | PB0 / TIM3_CH3 |
| 19  | D4 | PA12 / FDCAN1_TX |
| 20  | ~D5 | PA11 / FDCAN1_RX |
| 21  | ~D6 | PB1 / TIM3_CH4 |
| 22  | D7 | PB2 / TIM8_CH4N |
| 23  | D8 | PB4 / TIM3_CH1 |
| 24  | ~D9 | PB8 / TIM4_CH3 |
| 25  | ~D10 | PB9 / SPI2_SS / TIM4_CH4 |
| 26  | ~D11 | PB15 / SPI2_MOSI / TIM1_CH3N |
| 27  | D12 | PB14 / SPI2_MISO / TIM1_CH2N |
| 28  | D13 | PB13 / SPI2_SCK / TIM1_CH1N |
| 29  | GND | Ground |
| 30  | AREF | Analog reference |
| 31  | D20/SDA | PB11 / I2C2_SDA / TIM2_CH4 |
| 32  | D21/SCL | PB10 / I2C2_SCL / TIM2_CH3 |

## 2. New symbol: `nebula_symbols:Arduino_UNO_Q_Shield_Header_Corrected`

- 32 pins arranged 14+18 with the names above.
- Footprint property points to `nebula_footprints:Arduino_UNO_Q_Shield`.
- Pin 1 (BOOT, JANALOG) is marked with the square pad in the footprint.
- The old `Arduino_UNO_Q_Shield_Header` and `Arduino_UNO_Shield_2x20` remain in place so the current `J21` instance keeps the existing DRC/ERC baseline. Swapping `J21` to the corrected entries is a manual migration step.

## 3. J21 placement proposal

To keep the UNO Q board centered on the 125 × 120 mm Q-Shield:

```text
J21 footprint origin  ->  (15.71 mm, 33.33 mm)
UNO board on Q-Shield ->  x = 15.71 .. 84.29 mm
                         y = 33.33 .. 86.67 mm
```

This is a safe starting point. If it overlaps with already-placed components, move the origin in 2.54 mm steps (header pitch) so that the four mounting holes and the header rows stay on the 125 × 120 mm `Edge.Cuts`. The final approved origin used in the layout is `(5.08 mm, 35.56 mm)` (see `docs/INSIGHT_FABRICATION_ROADMAP.md`).

## 4. Keepout / cutout proposal

Add these zones on the Q-Shield **relative to the UNO Q board origin** (add the J21 `(x,y)` offset to convert to Q-Shield coordinates). Use `Dwgs.User` / `Cmts.User` for keepouts and `Edge.Cuts` for actual board slots where a connector or button must pass through the shield.

| Feature | Board-local rectangle (x) | Board-local rectangle (y) | Treatment |
|---|---|---|---|
| USB-C connector  | -3.0 .. 18.0 mm | 46.0 .. 59.0 mm | Edge.Cuts slot + all-layer keepout |
| Power button | 8.0 .. 14.0 mm | 50.5 .. 59.0 mm | Edge.Cuts slot + all-layer keepout |
| JCTL header | 12.0 .. 35.0 mm | 51.5 .. 59.0 mm | Keepout (cutout only if the header is tall enough to require a slot) |
| Power jack / JMEDIA | 55.0 .. 72.0 mm | 50.0 .. 59.0 mm | Edge.Cuts slot + all-layer keepout |
| SPI2 / JSPI | 62.0 .. 72.0 mm | 33.0 .. 53.0 mm | Keepout / partial cutout |
| QWIIC | 62.0 .. 72.0 mm | 15.0 .. 30.0 mm | Keepout |
| USB-C/PMIC tall parts (left edge) | -3.0 .. 6.0 mm | 30.0 .. 59.0 mm | Keepout |

Recommended clearance between the Q-Shield copper/placement and these zones: **2.0 mm** minimum, **1.5 mm** absolute minimum.

## 5. Important design note: I2C / A4-A5 conflict

On the UNO Q, `A4/D18` and `A5/D19` are **the same physical pins** as `I2C3_SDA` and `I2C3_SCL`. The old symbol treated SDA/SCL as separate pins, which cannot be routed independently on this connector. The corrected symbol reflects the hardware:

- I2C3 bus: pins 13 (A4/D18) and 14 (A5/D19).
- Alternative I2C2 bus: pins 31 (D20/SDA) and 32 (D21/SCL).

If the design requires both analog A4/A5 and an independent I2C, either use the **Qwiic** connector or the **I2C2** digital pins (31/32) and do not connect anything to pins 13/14 for analog.

## 6. Migration checklist

1. In **Schematic**, change `J21` symbol to `nebula_symbols:Arduino_UNO_Q_Shield_Header_Corrected`.
2. Reassign the existing Q-Shield nets to the new pin numbers using the table above.
3. In **PCB**, change `J21` footprint to `nebula_footprints:Arduino_UNO_Q_Shield`.
4. Move `J21` to the proposed `(15.71, 23.33)` origin (or adjusted location).
5. Add the keepout / cutout polygons from section 4.
6. Re-run DRC/ERC and re-route any broken tracks.

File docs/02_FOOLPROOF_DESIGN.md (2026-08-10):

# Nebula Q-Shield® — Diseño 100% Foolproof

> **Documento:** NQS-FP-002 · **Rev:** 1.0 · **Fecha:** Mayo 2026
>
> **Clasificación:** Ingeniería — Protección y Confiabilidad
>
> **Objetivo:** Garantizar que el Q-Shield® sobreviva a CUALQUIER error del usuario, condición ambiental adversa o fallo de componente sin daño permanente.

---

## 1. Filosofía Foolproof — Las 7 Capas de Protección

El diseño Q-Shield® implementa **7 capas de protección concéntricas** que aseguran que ningún error de usuario, transitorio eléctrico o fallo de componente pueda causar daño permanente al sistema.

```
    ┌───────────────────────────────────────────────────────────────┐
    │  CAPA 7: MONITOREO CONTINUO Y FAILSAFE POR FIRMWARE         │
    │  ┌───────────────────────────────────────────────────────┐   │
    │  │  CAPA 6: AISLAMIENTO GALVÁNICO                       │   │
    │  │  ┌───────────────────────────────────────────────┐   │   │
    │  │  │  CAPA 5: PROTECCIÓN TÉRMICA                   │   │   │
    │  │  │  ┌───────────────────────────────────────┐   │   │   │
    │  │  │  │  CAPA 4: LIMITACIÓN DE CORRIENTE      │   │   │   │
    │  │  │  │  ┌───────────────────────────────┐   │   │   │   │
    │  │  │  │  │  CAPA 3: SUPRESIÓN ESD/TVS    │   │   │   │   │
    │  │  │  │  │  ┌───────────────────────┐   │   │   │   │   │
    │  │  │  │  │  │  CAPA 2: POLARIDAD   │   │   │   │   │   │
    │  │  │  │  │  │  ┌───────────────┐   │   │   │   │   │   │
    │  │  │  │  │  │  │  CAPA 1:      │   │   │   │   │   │   │
    │  │  │  │  │  │  │  MECÁNICA     │   │   │   │   │   │   │
    │  │  │  │  │  │  └───────────────┘   │   │   │   │   │   │
    │  │  │  │  │  └───────────────────────┘   │   │   │   │   │
    │  │  │  │  └───────────────────────────────┘   │   │   │   │
    │  │  │  └───────────────────────────────────────┘   │   │   │
    │  │  └───────────────────────────────────────────────┘   │   │
    │  └───────────────────────────────────────────────────────┘   │
    └───────────────────────────────────────────────────────────────┘
```

---

## 2. CAPA 1 — Protección Mecánica

### 2.1 Conectores Keyed (Anti-Inserción Incorrecta)

Cada conector del Q-Shield® es **mecánicamente keyed** — es físicamente imposible conectarlo al revés o en el puerto equivocado.

| Conector | Tipo | Keying | Error que previene |
|---|---|---|---|
| Sondas pH/ORP/DO | BNC hembra | Bayoneta con latch | Polaridad inversa imposible |
| Sensores analógicos | JST-XH (2.54 mm) | Polarizado con tab | Inversión de pines imposible |
| I2C (GPS, RTC, Cell) | JST-SH 4-pin (Qwiic) | 1.0 mm polarizado | Estándar Qwiic — universal |
| Celda de carga | Terminal block con tornillo | 4-pin etiquetado | Color-coded: E+/E-/S+/S- |
| HMI UART | JST-XH 4-pin (2.54 mm) | Polarizado con tab | Inversión de pines imposible |
| Alimentación 12V | DC barrel jack | 2.1×5.5mm, center-positive | Diámetro impide jacks incorrectos |

### 2.2 Etiquetado y Serigrafía

Cada conector tiene impreso en la PCB (serigrafía):

```
    ┌──────────────────────────────────────┐
    │  J1 pH PROBE                         │
    │  ◄── BNC ──►   ⚠ LÍQUIDO AISLADO    │
    │                                       │
    │  J3 CO₂ PRESS          J5 NTC TEMP   │
    │  [VCC][OUT][GND]       [SIG][GND]    │
    │   +5V  AN   ⏚          AN   ⏚       │
    │                                       │
    │  J17 POWER 12V DC                    │
    │  [+12V][ ⏚ GND]                     │
    │  ⚠ MAX 15V              ⚡ FUSED 3A  │
    └──────────────────────────────────────┘
```

### 2.3 Protección Mecánica PCB

| Característica | Especificación |
|---|---|
| Agujeros de montaje | 4× M3, patrón Arduino UNO (spacing 53.34 × 50.8 mm) |
| Standoffs | 10 mm nylon (aislamiento eléctrico) |
| Conformal coating | Humiseal 1B73 o equivalente acrílico (opcional, recomendado para IP54) |
| Bordes PCB | Rounded 1 mm radius (previene microfisuras) |

---

## 3. CAPA 2 — Protección de Polaridad Inversa

### 3.1 Entrada de Alimentación 12V

**Error del usuario:** Conectar la fuente 12V con polaridad invertida.

**Protección:** Diodo Schottky serie (SS34) en línea de alimentación positiva.

```
    JACK 12V ──►[D2 SS34 Schottky]──► 12V_RAIL
                 │
                 ├── V_f = 0.5V @ 3A (pérdida mínima)
                 ├── V_RRM = 40V (soporta hasta 40V inverso)
                 └── I_F_max = 3A (suficiente para carga completa)

    Si usuario conecta al revés:
    ─12V ──►[D2 BLOQUEADO]──X── No llega corriente
                                 Corriente = 0 mA
                                 Sin daño
```

**Alternativa para producción (mayor eficiencia):** P-MOSFET en configuración ideal diode.

```
    JACK 12V ──►[Q_PMOS Si2301CDS]──► 12V_RAIL
                 │
                 Gate ← Tied to source vía R (auto-on con polaridad correcta)
                 │
                 ├── R_ds_on = 0.112Ω (pérdida: 0.112W @ 1A vs 0.5W del Schottky)
                 └── V_ds_max = -20V (protección bidireccional)
```

### 3.2 Protección en Conectores de Sensor

Cada conector JST incluye un diodo de clamp a GND que absorbe polaridad inversa:

| Conector | Diodo | V_clamp | Función |
|---|---|---|---|
| J3 (CO₂) | BAT54S dual | 0.3V | Clamp negativo + positivo |
| J5 (NTC) | BAT54S dual | 0.3V | Clamp negativo |
| J6 (Hum) | BAT54S dual | 0.3V | Clamp negativo + positivo |

### 3.3 Protección Salida Actuadores

Los MOSFETs de potencia (IRLZ44N) incluyen diodos body intrínsecos que protegen contra polaridad inversa en la carga del motor.

Los relays K1 y K2 tienen diodos flyback (1N4148W) que absorben la energía inductiva al abrir, evitando picos de tensión inversa.

---

## 4. CAPA 3 — Protección ESD y Supresión de Transitorios

### 4.1 Normativa de Referencia

| Ensayo | Norma | Nivel | Voltaje |
|---|---|---|---|
| ESD contacto | IEC 61000-4-2 | Level 4 | ±8 kV |
| ESD aire | IEC 61000-4-2 | Level 4 | ±15 kV |
| EFT (burst) | IEC 61000-4-4 | Level 3 | ±2 kV |
| Surge | IEC 61000-4-5 | Level 2 | ±1 kV |

### 4.2 Dispositivos TVS por Puerto

| Puerto | Dispositivo TVS | V_clamp | C_junction | Norma cubierta |
|---|---|---|---|---|
| Entrada 12V | SMAJ15A | 24.4V @ 1A | — | IEC 61000-4-5 Level 2 |
| Canales ADC (A0–A3) | PESD5V0S1BSF | 9.8V @ 1A | 0.4 pF | IEC 61000-4-2 Level 4 |
| Canal ADC (A4–A5) | PESD3V3S1BSF | 7.5V @ 1A | 0.4 pF | IEC 61000-4-2 Level 4 |
| I2C SDA/SCL | PESD3V3S2USF | 7.5V dual | 0.4 pF | IEC 61000-4-2 Level 4 |
| GPIO digitales | PESD5V0S1BSF | 9.8V | 0.3 pF | IEC 61000-4-2 Level 4 |
| HMI UART TX/RX | PESD3V3S2USF | 7.5V dual | 0.4 pF | IEC 61000-4-2 Level 4 |

### 4.3 Diseño de PCB para ESD

```
    Reglas de ruteo para protección ESD:
    
    1. TVS lo más cerca posible del conector (< 5 mm)
    2. Pista del conector al TVS: directa, sin vías
    3. Vía de tierra del TVS al plano GND: múltiples vías (≥ 2)
    4. Guard ring de GND alrededor de todos los conectores
    5. Sin pistas de señal bajo los conectores
```

---

## 5. CAPA 4 — Limitación de Corriente

### 5.1 Fusible Principal (Entrada 12V)

| Parámetro | Valor | Componente |
|---|---|---|
| Tipo | PTC recuperable (Polyfuse) | MF-MSMF110/24X-2 |
| I_hold | 1.1 A | Corriente continua sin disparo |
| I_trip | 2.2 A | Corriente de disparo |
| V_max | 24V | Voltaje máximo operativo |
| Tiempo de respuesta | < 5 s @ 2× I_hold | Respuesta rápida |
| Encapsulado | 1812 SMD | Compatible reflow |

**Escenario de fallo:** Si un usuario cortocircuita la salida 12V, el PTC se calienta y aumenta su resistencia de mΩ a kΩ en < 5 segundos, cortando la corriente. Al eliminar el cortocircuito, el PTC se enfría y el sistema se recupera automáticamente. **No necesita reemplazo.**

### 5.2 Limitación por Canal de Actuador

| Canal | Componente | Límite | Protección |
|---|---|---|---|
| Motor bomba | Shunt 0.1Ω + comparador | 2A max | Shutdown driver IR2104 |
| Chiller relay | PTC 1A (0805) | 1A max | Auto-reset |
| CO₂ solenoide | PTC 0.5A (0805) | 0.5A max | Auto-reset |
| CO₂ regulador PWM | R_sense en MOSFET | 1A max | Firmware cutoff |

### 5.3 Protección de Entradas Analógicas

Cada entrada analógica incluye una resistencia serie de 1 kΩ que limita la corriente en caso de sobretensión a:

```
    I_max = (V_max - V_clamp_TVS) / R_serie
    I_max = (30V - 5V) / 1kΩ = 25 mA

    El TVS absorbe el exceso. El ADC del STM32 nunca ve más de V_clamp.
    Los diodos de protección internos del STM32 pueden manejar hasta 5 mA,
    pero nunca se activan porque el TVS externo clampea primero.
```

---

## 6. CAPA 5 — Protección Térmica

### 6.1 Monitoreo de Temperatura de la PCB

| Componente | Sensor | Ubicación | Umbral |
|---|---|---|---|
| NTC integrado | 10 kΩ NTC (en PCB) | Cerca del regulador buck | Shutdown @ 85°C |
| Thermal pad | Pad de cobre expuesto | Bajo U1 (TPS54302) | Disipación: 0.5W |

### 6.2 Protección Térmica del Regulador Buck

El TPS54302 incluye protección térmica interna:

| Parámetro | Valor |
|---|---|
| Thermal shutdown | 165°C (junction) |
| Thermal hysteresis | 15°C |
| θ_JA (SOT-23-6 con plano GND) | 60°C/W |
| Potencia disipada máx. | (12V-5V) × 0.5A × (1-η) ≈ 0.35W @ η=90% |
| T_junction estimada | T_amb + 0.35W × 60°C/W = T_amb + 21°C |
| T_junction a 55°C ambiente | 76°C (muy debajo de 165°C shutdown) |

### 6.3 Protección Térmica de Actuadores

| Componente | Protección | Método |
|---|---|---|
| MOSFETs IRLZ44N | θ_JA = 62°C/W, P_max = 1.6W @ 55°C | Pad de cobre 10×10 mm |
| Relays | Rated 5A, uso a < 1A | Derating > 80% |
| Optoacopladores | I_LED < 10 mA (rated 50 mA) | Derating > 80% |

### 6.4 Diseño Térmico PCB

```
    Reglas de layout térmico:

    1. Vías térmicas bajo reguladores (array 3×3, 0.3 mm)
    2. Plano de cobre expuesto (thermal pad) en cara inferior bajo U1
    3. Componentes de potencia (MOSFETs, relays) en borde de PCB
       para convección natural
    4. Espacio mínimo 5 mm entre componentes térmicos
    5. No colocar sensores analógicos cerca de fuentes de calor
```

---

## 7. CAPA 6 — Aislamiento Galvánico

### 7.1 Aislamiento Sensores Electroquímicos

| Barrera | Componente | Voltaje | Función |
|---|---|---|---|
| pH ↔ MCU | Atlas ISCCB-2 (externo) | 1 kV DC | Elimina ground loops |
| ORP ↔ MCU | Atlas ISCCB-2 (externo) | 1 kV DC | Elimina ground loops |
| DO ↔ MCU | Atlas ISCCB-2 (externo) | 1 kV DC | Elimina ground loops |
| I2C aislado (on-board) | ISO7721DR | 2.5 kV RMS | Backup si no hay Atlas |

### 7.2 Aislamiento Actuadores ↔ MCU

| Barrera | Componente | Voltaje | Función |
|---|---|---|---|
| GPIO ↔ Motor driver | PC817X2NIP | 5 kV pk | Protege MCU de EMI motor |
| GPIO ↔ Relay chiller | PC817X1NIP | 5 kV pk | Aislamiento inductivo |
| GPIO ↔ Relay CO₂ | PC817X1NIP | 5 kV pk | Aislamiento inductivo |

### 7.3 Arquitectura de Tierra

```
    ┌──────────────────────────────────────────────────────┐
    │           PLANO GND CONTINUO (Capa 2)                │
    │           un único net: GND                          │
    │                                                      │
    │   Analógico        Digital          Potencia         │
    │   Sensores ADC     I2C, GPIO        MOSFETs          │
    │   Op-amps          UART             Relays           │
    │      │                │                │             │
    │      ▼                ▼                ▼             │
    │   vías locales     vías locales     vías locales     │
    │   (<2 mm del pad)  (<2 mm del pad)  (múltiples)      │
    │      │                │                │             │
    │      └────────────────┴────────────────┘             │
    │                       │                              │
    │              plano continuo sin cortes               │
    └───────────────────────┬──────────────────────────────┘
                            ▼
              Conector de entrada de alimentación

    ═══════ BARRERA GALVÁNICA (nets flotantes, NO unir a GND) ═══════

    GND_ISO_PH   ← U6  AMC1301 + T1
    GND_ISO_ORP  ← U9  AMC1301 + T2
    GND_ISO_DO   ← U13 AMC1301 + T3
    GND_ISO      ← U21 ISO1541 (I2C)
```

**Tierra unificada:** no se parte el plano en AGND/DGND/PGND. El efecto que
busca el star grounding se consigue a nivel de componente — cada bloque tiene
su desacoplo local y sus vías al plano a menos de 2 mm del pad, así que ve un
retorno de baja impedancia sin necesidad de cortar el cobre. Partir el plano
introduce discontinuidades en el camino de retorno que empeoran la EMI.

**El aislamiento real** lo dan los AMC1301 con sus fuentes flotantes
(SN6501 + transformador), no una segunda tierra. Esos nets `GND_ISO_*` sí son
genuinamente flotantes y nunca deben conectarse al plano principal.

---

## 8. CAPA 7 — Monitoreo y Failsafe por Firmware

### 8.1 Watchdog de Hardware

| Parámetro | Valor |
|---|---|
| Tipo | Hardware IWDG (STM32U585) |
| Timeout | 8 segundos |
| Feed interval | 4 segundos |
| Acción al expirar | Hard reset MCU |
| Detección post-reset | Flag `RCC_CSR.IWDGRSTF` — reporta vía IPC |

### 8.2 Monitoreo de Voltajes por ADC

El firmware lee periódicamente los voltajes de los rails de potencia:

| Rail | Canal ADC | Divisor | Umbral bajo | Umbral alto | Acción |
|---|---|---|---|---|---|
| 12V | ADC interno | 10k/3.3k | < 10.5V | > 14V | Alerta MQTT + LED rojo |
| 5V | ADC interno | 10k/10k | < 4.5V | > 5.5V | Alerta MQTT |
| 3.3V | VREFINT | — | < 3.0V | > 3.6V | Error crítico |

### 8.3 Failsafe de Actuadores

| Actuador | Condición de fallo | Acción automática |
|---|---|---|
| CO₂ solenoide | Presión > 180 kPa | **CIERRE INMEDIATO** (latching fault) |
| CO₂ solenoide | Pérdida de comunicación IPC > 10s | Cierre (normalmente cerrado — fail-safe) |
| CO₂ solenoide | Watchdog reset | Cierre (GPIO baja al reset) |
| Chiller relay | Ciclo on < 60s | Bloqueo (protección compresor) |
| Chiller relay | Ciclo off < 120s | Bloqueo (protección compresor) |
| Bomba motor | Corriente > 2A | Shutdown driver (hardware) |
| Bomba motor | Pérdida de comunicación | Motor detenido (PWM = 0 al reset) |
| Todos | Temperatura PCB > 85°C | Shutdown todos los actuadores |

### 8.4 Store-and-Forward (Resiliencia de Datos)

| Nivel | Capacidad | Trigger | Acción |
|---|---|---|---|
| MCU buffer | 64 entradas | IPC NACK o timeout | Almacena en circular buffer SRAM |
| MPU SQLite | 10,000 entradas | immudb inaccesible | WAL mode, replay cada 30s |

> **Garantía:** No se pierde ningún dato de sensor, incluso con cortes de energía, reinicios del sistema o fallos de comunicación.

---

## 9. Matriz de Escenarios de Error

### 9.1 Errores de Usuario

| # | Escenario | Capa | Protección | Resultado |
|---|---|---|---|---|
| 1 | Conecta fuente 12V al revés | 2 | Schottky SS34 bloquea | Sin daño, sin función |
| 2 | Conecta fuente 24V en vez de 12V | 3+4 | TVS SMAJ15A clampea + PTC dispara | PTC se recupera solo |
| 3 | Cortocircuita terminal de sensor | 4 | R serie 1kΩ + TVS | Sin daño al ADC |
| 4 | Toca conector con descarga estática | 3 | TVS < 0.4 pF | Sin daño, sin error de lectura |
| 5 | Conecta sensor en puerto incorrecto | 1 | Conectores keyed JST | Físicamente imposible |
| 6 | Alimenta 12V sin sensor conectado | 4 | Pull-down 10MΩ en cada canal | Lee 0V (sin flotante) |
| 7 | Desconecta HMI en caliente | 3 | ESD protection UART (PESD3V3S2USF) | Sin daño |
| 8 | Sumerge cable sensor en agua | 6 | Aislamiento galvánico | Sin ground loop |
| 9 | Cortocircuita motor bomba | 4 | PTC + driver overcurrent | Auto-shutdown, auto-reset |
| 10 | Olvida desconectar CO₂ | 7 | Presión max 180 kPa → cierre automático | Seguro (latching) |

### 9.2 Fallos Ambientales

| # | Escenario | Capa | Protección | Resultado |
|---|---|---|---|---|
| 11 | Rayo cercano (surge en línea 12V) | 3 | SMAJ15A + PTC | TVS absorbe, PTC protege |
| 12 | Corte de energía durante escritura | 7 | Store-forward + WAL SQLite | Datos recuperados al reiniciar |
| 13 | Temperatura ambiente > 55°C | 5 | Derating + thermal shutdown | Regulador se apaga, reinicia al enfriar |
| 14 | Condensación por lluvia | 1 | Conformal coating + IP54 enclosure | Funcionalidad mantenida |
| 15 | Vibración por maquinaria | 1 | Montaje M3 + terminal blocks con tornillo | Conexiones seguras |

### 9.3 Fallos de Componente

| # | Escenario | Capa | Protección | Resultado |
|---|---|---|---|---|
| 16 | Sensor pH falla (circuito abierto) | 7 | Pull-down 10MΩ → lectura 0V detectada | Alerta MQTT, dato marcado FAULT |
| 17 | Op-amp falla | 7 | Lectura fuera de rango detectada por firmware | Alerta, sensor deshabilitado |
| 18 | MOSFET falla en corto | 4 | PTC en línea de motor | Motor limitado, PTC dispara |
| 19 | Relay falla pegado | 7 | Watchdog → todos los GPIO a LOW | Chiller/CO₂ limitados por protección |
| 20 | Regulador 5V falla | — | Regulador tiene OVP/UVP internos | MCU se reinicia, datos en flash |

---

## 10. Resumen de Componentes de Protección

| Ref | Componente | Cantidad | Función |
|-----|---|---|---|
| D1 | SMAJ15A (TVS) | 1 | Protección surge entrada 12V |
| D2 | SS34 (Schottky) | 1 | Polaridad inversa entrada |
| D3–D6 | PESD5V0S1BSF / PESD3V3S1BSF | 6 | ESD por canal analógico |
| D7–D8 | PESD3V3S2USF | 1 | ESD bus I2C (dual) |
| D9–D13 | SS34 | 5 | Flyback actuadores |
| D_HMI | PESD3V3S2USF | 1 | ESD HMI UART dual-line |
| F1 | MF-MSMF110 (PTC) | 1 | Fusible recuperable principal |
| F2–F4 | PTC 0805 | 3 | Fusibles por actuador |
| U8–U11 | PC817 | 4 | Optoacoplamiento actuadores |
| U4 | ISO7721DR | 1 | Aislamiento I2C galvánico |
| R_pull-down | 10 MΩ × 6 | 6 | Anti-flotante canales ADC |
| R_serie | 1 kΩ × 6 | 6 | Limitación corriente canales ADC |
| BAT54S | Dual Schottky clamp × 3 | 3 | Clamp polaridad conectores |

**Total componentes de protección:** ~40 piezas dedicadas exclusivamente a protección.

---

## 11. Certificaciones de Protección Aplicables

| Ensayo | Norma | Nivel Requerido | Nivel Alcanzado |
|---|---|---|---|
| ESD contacto | IEC 61000-4-2 | Level 3 (±6 kV) | **Level 4 (±8 kV)** |
| ESD aire | IEC 61000-4-2 | Level 3 (±8 kV) | **Level 4 (±15 kV)** |
| EFT/Burst | IEC 61000-4-4 | Level 2 (±1 kV) | **Level 3 (±2 kV)** |
| Surge | IEC 61000-4-5 | Level 1 (±0.5 kV) | **Level 2 (±1 kV)** |
| Polaridad inversa | — | No destructivo | **No destructivo, auto-recovery** |
| Sobrecorriente | — | Auto-recovery | **PTC auto-reset** |
| Térmica | — | Shutdown seguro | **Auto-shutdown, auto-recovery** |

---

*Documento NQS-FP-002 Rev 1.0 — Nebula Ecosystem® — 100% Foolproof by Design*

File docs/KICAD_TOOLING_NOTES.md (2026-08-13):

# Notas técnicas de tooling KiCad — cosas que cuestan horas si no las sabés

Esto es la destilación de lo aprendido armando `tools/route_fase6.py` y
`tools/replan_analog_block.py` (Fase 6). No es historia de qué se hizo —
para eso está `docs/CLAUDE_FASE6_REPORT.md` — es una referencia técnica para
la próxima vez que alguien (agente o humano) escriba o corra un script
`pcbnew`/`kicad-cli` sobre este repo.

## 1. `kicad-cli` necesita el `.kicad_pro` Y el `.kicad_dru` con el mismo basename

Si copiás `kicad/nebula_qshield.kicad_pcb` a otro nombre (por ejemplo para
probar un script sin tocar el archivo real) y corrés `kicad-cli pcb drc`
sobre esa copia, KiCad busca automáticamente `<basename>.kicad_pro` y
`<basename>.kicad_dru` **al lado**, con el mismo nombre base. Si no los
encuentra, corre con reglas de KiCad genéricas en vez de las reglas custom
del proyecto — y reporta violaciones que no existen en el board real.

Esto costó una sesión entera de confusión: una prueba temprana reportó
**217 violaciones** (vías de 0.5mm marcadas como ilegales, etc.) que
resultaron ser 100% falsos positivos por este motivo. Al copiar también
`.kicad_pro` y `.kicad_dru` con el mismo basename, bajó a las violaciones
reales (varias decenas, después 0).

**Regla:** cualquier script/test que copie el `.kicad_pcb` a otro lado tiene
que copiar también `.kicad_pro` y `.kicad_dru` con el mismo basename.

## 2. El ancho de netclass tiene DOS valores distintos — no confundirlos

- `kicad/nebula_qshield.kicad_pro` → `net_settings.classes[].track_width` es
  el ancho **preferido/default** — lo que el editor dibuja cuando arrancás
  un track nuevo a mano. No es un piso.
- `kicad/nebula_qshield.kicad_dru` tiene reglas custom (`Power_Rails`,
  `High_Current_12V`, `Analog_Signals`, `I2C_Bus`, `Relay_HV_Contacts`,
  `Signal_Default`) que definen el **mínimo real que el DRC exige**, y no
  coincide con el "preferido" de arriba:

  | Netclass | Ancho preferido (`.kicad_pro`) | Mínimo real (`.kicad_dru`) |
  |---|---|---|
  | Default | 0.25 mm | 0.20 mm |
  | Analog | 0.25 mm | 0.25 mm |
  | I2C | 0.25 mm | 0.25 mm |
  | Power | 0.50 mm | **0.50 mm** |
  | HighCurrent | 1.50 mm | **0.50 mm** |
  | RelayHV | 1.00 mm | 1.00 mm |

  (Vía y clearance: `.kicad_dru` también fija `via_diameter` mínimo 0.5mm
  para Signal_Default/Power/HighCurrent vs. los 0.6mm que sugiere
  `.kicad_pro` — el board admite vías más chicas de lo que el `.kicad_pro`
  hace parecer, PERO el piso real varía por netclass, no es un número único.)
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

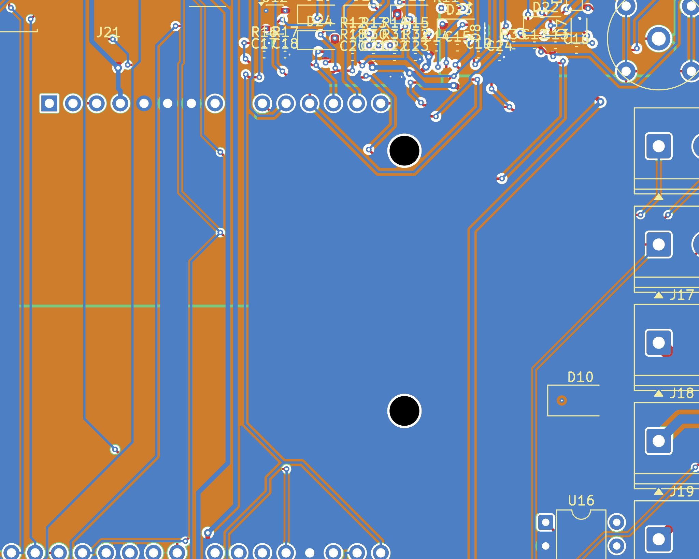
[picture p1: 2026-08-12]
docs/layout_fase6.png

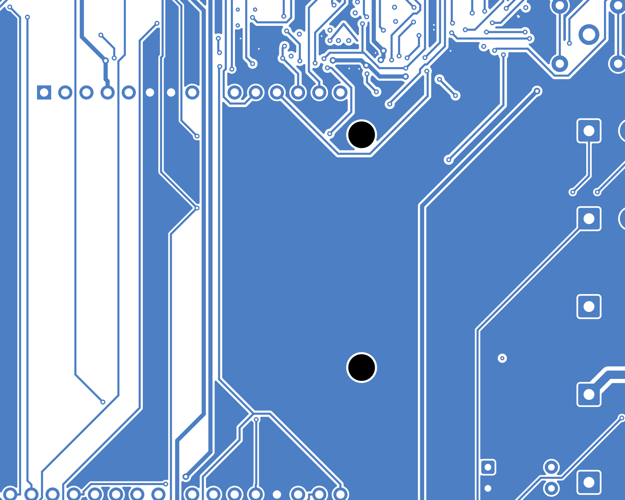
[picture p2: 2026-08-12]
docs/layout_bcu.png

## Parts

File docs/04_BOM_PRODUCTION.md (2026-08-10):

# Nebula Q-Shield® — Bill of Materials (BOM) de Producción

> **Documento:** NQS-BOM-004 · **Rev:** 1.0 · **Fecha:** Mayo 2026
>
> **Clasificación:** Producción — Lista de Materiales
>
> **PCB:** Q-Shield v1.0 · **Tier base:** Essential® / **Target producción:** Insight® / **Máximo:** Signature® · **Total placements:** 163 unique · **DNP field = tiers where NOT populated**
>
> **Todos los componentes son RoHS 3 conformes (2011/65/EU + 2015/863)**

---

## 1. Resumen de Costos

| Categoría | Componentes | Costo unitario (100 uds) | Costo unitario (1000 uds) |
|---|---|---|---|
| Protección y potencia | 22 | $4.85 | $3.90 |
| Analógico (sensores) | 28 | $3.20 | $2.60 |
| Digital (I2C, RS485 bridge, HX711) | 18 | $4.50 | $3.60 |
| Actuadores (drivers) | 18 | $5.50 | $4.40 |
| Conectores | 21 | $6.30 | $5.10 |
| Pasivos (R, C) | 45 | $1.20 | $0.95 |
| PCB fabricación (4 capas, ENIG) | 1 | $8.00 | $4.50 |
| **TOTAL PCB Q-Shield®** | **153** | **$33.55** | **$25.05** |

> Los precios son estimados para componentes comprados en Digi-Key/Mouser con cantidades de 100 y 1000 unidades respectivamente. Los sensores y actuadores externos NO están incluidos (ver `HARDWARE_BUYING_GUIDE.md`).

---

## 2. BOM Completa — Componentes de Protección y Potencia

| Ref | Qty | Descripción | Valor | Encapsulado | MPN | Digi-Key PN | Precio (100+) |
|-----|-----|---|---|---|-----|---|---|
| D1 | 1 | TVS diode, bidirectional | 15V, 400W | SMA | SMAJ15A | SMAJ15ALFCT-ND | $0.35 |
| D2 | 1 | Schottky diode | 40V, 3A | SMA | SS34 | SS34-E3/57TCT-ND | $0.28 |
| F1 | 1 | PTC resettable fuse | 1.1A hold / 2.2A trip | 1812 | MF-MSMF110/24X-2 | MF-MSMF110/24X-2CT-ND | $0.42 |
| F2 | 1 | PTC resettable fuse | 1.0A hold | 0805 | MF-PSMF110X-2 | MF-PSMF110X-2CT-ND | $0.18 |
| F3 | 1 | PTC resettable fuse | 0.5A hold | 0805 | MF-PSMF050X-2 | MF-PSMF050X-2CT-ND | $0.15 |
| F4 | 1 | PTC resettable fuse | 0.5A hold | 0805 | MF-PSMF050X-2 | MF-PSMF050X-2CT-ND | $0.15 |
| U1 | 1 | Buck converter | 4.5–28V in, 5V/3A out | SOT-23-6 | TPS54302DDCR | 296-50420-1-ND | $1.25 |
| L1 | 1 | Power inductor | 4.7 μH, 4A sat | 4×4×2mm | 744043004700 | 732-1260-1-ND | $0.48 |
| U2 | 1 | LDO regulator | 3.3V, 800mA | SOT-223 | AMS1117-3.3 | AMS1117-3.3CT-ND | $0.32 |
| FB1 | 1 | Ferrite bead | 600Ω @ 100MHz, 2A | 1206 | BLM31PG601SN1L | 490-5222-1-ND | $0.12 |

---

## 3. BOM Completa — Bloque Analógico

| Ref | Qty | Descripción | Valor | Encapsulado | MPN | Digi-Key PN | Precio (100+) |
|-----|-----|---|---|---|-----|---|---|
| U3 | 2 | Dual op-amp, rail-to-rail | 1 MHz GBW | SOIC-8 | MCP6002-I/SN | MCP6002-I/SN-ND | $0.52 |
| D3 | 1 | TVS ESD, unidirectional | 5V clamp, 0.4pF | SOD-323F | PESD5V0S1BSF | 568-13204-1-ND | $0.15 |
| D4 | 1 | TVS ESD, unidirectional | 5V clamp | SOD-323F | PESD5V0S1BSF | 568-13204-1-ND | $0.15 |
| D5 | 1 | TVS ESD, unidirectional | 3.3V clamp | SOD-323F | PESD3V3S1BSF | 568-13206-1-ND | $0.15 |
| D6 | 1 | TVS ESD, unidirectional | 5V clamp | SOD-323F | PESD5V0S1BSF | 568-13204-1-ND | $0.15 |
| D7_1 | 1 | TVS ESD, unidirectional | 3.3V clamp | SOD-323F | PESD3V3S1BSF | 568-13206-1-ND | $0.15 |
| D8_1 | 1 | TVS ESD, unidirectional | 5V clamp | SOD-323F | PESD5V0S1BSF | 568-13204-1-ND | $0.15 |
| R3–R5, R9 | 4 | Resistor, thin film | 1 kΩ ±1% | 0402 | CRCW04021K00FKED | 541-1.00KLCT-ND | $0.02 |
| C11–C14 | 4 | Capacitor, MLCC | 100 nF X7R 50V | 0402 | CL05B104KO5NNNC | 1276-1001-1-ND | $0.01 |
| R4, R_PD | 6 | Resistor, pull-down | 10 MΩ ±5% | 0402 | CRCW040210M0JNED | 541-10.0MJCT-ND | $0.01 |
| R8 | 1 | Resistor, NTC series | 10 kΩ ±1% | 0402 | CRCW040210K0FKED | 541-10.0KLCT-ND | $0.02 |

---

## 4. BOM Completa — Bloque I2C y Digital

| Ref | Qty | Descripción | Valor | Encapsulado | MPN | Digi-Key PN | Precio (100+) |
|-----|-----|---|---|---|-----|---|---|
| R10, R11 | 2 | Resistor, pull-up I2C | 4.7 kΩ ±1% | 0402 | CRCW04024K70FKED | 541-4.70KLCT-ND | $0.02 |
| D7, D8 | 1 | TVS ESD, dual-line I2C | 3.3V clamp, 0.5pF | SOT-23-3 | PESD3V3S2USF | 568-13207-1-ND | $0.22 |
| U4 | 1 | Digital isolator, 2-ch | 100 Mbps, 2.5kV | SOIC-8 | ISO7721DR | 296-46893-1-ND | $1.85 |
| U6 | 1 | 24-bit ADC, load cell | 80 SPS, gain 128 | SOP-16 | HX711 | — (LCSC: C124335) | $0.65 |
| R12 | 1 | Resistor, pull-up | 10 kΩ ±5% | 0402 | CRCW040210K0JNED | 541-10.0KJCT-ND | $0.01 |
| C19, C20 | 2 | Capacitor, desacoplo HX711 | 100 nF + 10 μF | 0402 + 0805 | — | — | $0.03 |
| U22 | 1 | I2C-to-UART bridge | SC16IS740, 64-byte FIFO | TSSOP-16 | SC16IS740IPW/Q900 | 568-13068-1-ND | $1.85 |
| U23 | 1 | Single inverter | SN74LVC1G04 | SOT-353/SC-70-5 | SN74LVC1G04DCKR | 296-11602-1-ND | $0.35 |
| Y1 | 1 | Crystal | 1.8432 MHz | HC-49-SD SMD | ABLS-1.8432MHZ-B4-T | 535-9930-1-ND | $0.45 |
| C31, C32 | 2 | Capacitor, carga cristal | 22 pF C0G 50V | 0402 | CL05C220JB5NNNC | 1276-1013-1-ND | $0.01 |
| C33 | 1 | Capacitor, desacoplo U22 | 100 nF X7R 50V | 0402 | CL05B104KO5NNNC | 1276-1001-1-ND | $0.01 |
| R38 | 1 | Resistor, pull-up IRQ | 10 kΩ ±1% | 0402 | CRCW040210K0FKED | 541-10.0KLCT-ND | $0.02 |

---

## 5. BOM Completa — Bloque Actuadores

| Ref | Qty | Descripción | Valor | Encapsulado | MPN | Digi-Key PN | Precio (100+) |
|-----|-----|---|---|---|-----|---|---|
| U7 | 1 | Half-bridge gate driver | 600V, bootstrap | SOIC-8 | IR2104SPBF | IR2104SPBF-ND | $1.45 |
| Q1, Q2 | 2 | N-MOSFET, logic-level | 55V, 47A, 22mΩ | TO-220AB | IRLZ44NPBF | IRLZ44NPBF-ND | $1.10 |
| Q3, Q4 | 2 | N-MOSFET, small signal | 60V, 300mA | SOT-23 | 2N7002 | 2N7002-FDICT-ND | $0.08 |
| Q5 | 1 | N-MOSFET, logic-level | 55V, 47A | TO-220AB | IRLZ44NPBF | IRLZ44NPBF-ND | $1.10 |
| K1, K2 | 2 | Relay, SPST-NO | 12V coil, 5A/250VAC | THT | HF46F-12-HS1 | 255-5799-ND | $1.20 |
| U8, U9 | 2 | Optocoupler, dual | CTR 50–600% | DIP-8 | PC817X2NIP | — (Mouser: 852-PC817X2NIP0F) | $0.35 |
| U10, U11 | 2 | Optocoupler, single | CTR 50–600% | DIP-4 | PC817X1NIP | — (Mouser: 852-PC817X1NIP0F) | $0.18 |
| D9–D13 | 5 | Schottky diode, flyback | 40V, 3A | SMA | SS34 | SS34-E3/57TCT-ND | $0.28 |
| D11_2, D12_2 | 2 | Signal diode, flyback relay | 100V, 200mA | SOD-323 | 1N4148W | 1N4148WX-TPMSCT-ND | $0.03 |
| R13–R20 | 8 | Resistor, current limit | 1 kΩ ±5% | 0402 | CRCW04021K00JNED | 541-1.00KJCT-ND | $0.01 |
| C21, C28, C29 | 3 | Capacitor, desacoplo driver | 100 nF X7R | 0402 | CL05B104KO5NNNC | 1276-1001-1-ND | $0.01 |

---

## 6. BOM Completa — Conectores

| Ref | Qty | Descripción | Pines | MPN | Digi-Key PN | Precio (100+) |
|-----|-----|---|---|-----|---|---|
| J1 | 1 | BNC receptacle, panel mount | 1 | 31-221-RFX | ARF1065-ND | $1.85 |
| J2 | 1 | BNC receptacle, panel mount | 1 | 31-221-RFX | ARF1065-ND | $1.85 |
| J3 | 1 | JST-XH header, right angle | 3 | B3B-XH-A(LF)(SN) | 455-2248-ND | $0.15 |
| J4 | 1 | BNC receptacle, panel mount | 1 | 31-221-RFX | ARF1065-ND | $1.85 |
| J5 | 1 | JST-XH header, right angle | 2 | B2B-XH-A(LF)(SN) | 455-2247-ND | $0.12 |
| J6 | 1 | JST-XH header, right angle | 3 | B3B-XH-A(LF)(SN) | 455-2248-ND | $0.15 |
| J7–J13 | 7 | JST-SH header (Qwiic compat.) | 4 | SM04B-SRSS-TB(LF)(SN) | 455-1804-1-ND | $0.32 |
| J14 | 1 | Terminal block, rising clamp | 4 | 1757242 (Phoenix Contact) | 277-1274-ND | $0.85 |
| J_HMI | 1 | JST-XH header, HMI UART | 4 (5V/TX/RX/GND) | B4B-XH-A(LF)(SN) | 455-2249-ND | $0.15 |
| J17 | 1 | DC barrel jack, 2.1×5.5mm | 3 | PJ-002AH | CP-002AH-ND | $0.75 |
| J18–J20 | 3 | Terminal block, 2-pin | 2 | 1757229 (Phoenix Contact) | 277-1273-ND | $0.52 |
| J21 | 1 | Arduino UNO Q shield header | 32 | — (Arduino UNO R3/Q shield header set) | — | $1.50 |

---

## 7. BOM Completa — Pasivos (Reguladores)

| Ref | Qty | Descripción | Valor | Encapsulado | MPN | Precio (100+) |
|-----|-----|---|---|---|-----|---|
| C1 | 1 | MLCC, input filter | 100 μF 25V X5R | 1210 | GRM32ER61E107ME20L | $0.85 |
| C2 | 1 | Electrolytic, bulk | 470 μF 25V | Ø10×12.5 | UCD1E471MNL1GS | $0.45 |
| C3, C4 | 2 | MLCC, buck input | 22 μF 25V X5R | 0805 | GRM21BR61E226ME44L | $0.28 |
| C5, C6 | 2 | MLCC, buck output | 47 μF 10V X5R | 0805 | GRM21BR61A476ME15L | $0.35 |
| C7 | 1 | MLCC, bootstrap | 100 nF 50V X7R | 0402 | CL05B104KO5NNNC | $0.01 |
| C8 | 1 | MLCC, LDO input | 10 μF 10V X5R | 0805 | GRM21BR61A106KE19L | $0.08 |
| C9 | 1 | MLCC, LDO output | 22 μF 10V X5R | 0805 | GRM21BR61A226ME44L | $0.12 |
| C10 | 1 | Tantalum, LDO stab. | 10 μF 10V | 1206 | T491A106M010AT | $0.18 |
| C23–C29 | 7 | MLCC, IC decoupling | 100 nF 50V X7R | 0402 | CL05B104KO5NNNC | $0.01 |
| R1 | 1 | Resistor, feedback top | 100 kΩ ±1% | 0402 | CRCW0402100KFKED | $0.02 |
| R2 | 1 | Resistor, feedback bot | 24.9 kΩ ±1% | 0402 | CRCW040224K9FKED | $0.02 |

---

## 8. BOM Completa — LEDs Indicadores

| Ref | Qty | Descripción | Color | Encapsulado | MPN | Precio (100+) |
|-----|-----|---|---|---|-----|---|
| LED1 | 1 | LED indicator | Rojo | 0603 | 150060RS75000 | $0.05 |
| LED2 | 1 | LED indicator | Verde | 0603 | 150060GS75000 | $0.05 |
| LED3 | 1 | LED indicator | Azul | 0603 | 150060BS75000 | $0.08 |
| R_LED1 | 1 | Resistor, LED current | 4.7 kΩ ±5% | 0402 | CRCW04024K70JNED | $0.01 |
| R_LED2 | 1 | Resistor, LED current | 330 Ω ±5% | 0402 | CRCW0402330RJNED | $0.01 |
| R_LED3 | 1 | Resistor, LED current | 100 Ω ±5% | 0402 | CRCW0402100RJNED | $0.01 |

---

## 9. BOM Completa — ESD Protection (HMI UART)

| Ref | Qty | Descripción | Valor | Encapsulado | MPN | Digi-Key PN | Precio (100+) |
|-----|-----|---|---|---|-----|---|---|
| D_HMI | 1 | ESD protection, HMI UART dual-line | 3.3V dual, 0.4pF | SOT-23-3 | PESD3V3S2USF | 568-13207-1-ND | $0.22 |

---

## 10. BOM Completa — Sensor Clamp Diodes

| Ref | Qty | Descripción | Valor | Encapsulado | MPN | Precio (100+) |
|-----|-----|---|---|---|-----|---|
| D_CL1–D_CL3 | 3 | Dual Schottky, sensor clamp | 30V, 200mA | SOT-23-3 | BAT54S | $0.06 |

---

## 11. Componentes por Tier (DNP en tiers inferiores)

**Convención DNP:** el campo `DNP` indica los tiers en los que el componente **NO** se pobla. `NO` = poblado en todos los tiers; `Essential` = DNP en Essential (poblado en Insight/Signature); `Essential,Insight` = DNP en Essential/Insight (poblado en Signature); `Essential,Insight,Signature`/`All` = DNP siempre; `Optional` = no incluido por defecto.

### Essential (Componentes a poblar: 88 de 163)

- Sí: GPS (J8), RTC/timestamp (J9), temperatura (J6), pH (J2 + front-end U4-U6/T1), ORP (J3 + U7-U9/T2), watchdog (U3/R35/C11), HMI (J20), header Arduino UNO Q (J21), pull-ups I2C (R36/R37), protecciones ESD (D15-D18), conectores Qwiic/EZO, power management.
- No poblar: CO₂ presión (J4, U10, D5/R11/C18/R12), DO (J5, U11-U13/T3 + D23/D24/C30), celdas de carga (HX711 U14, J15, R21/C25/C26), motor recirculación (U16-U17, Q1-Q2, J17), solenoide gas (U18, Q3, K1, J18), chiller (U19, Q4, K2, J19), RS485 Hamilton (U15, U22-U23, Y1, C31-C33, R38, J16), sensor humedad (J7, D8, R17/R18/C23), válvula PWM (U20, Q5, D14, R28, C27, J22) y J10 (cell density Qwiic).

### Insight (Componentes a poblar: 137 de 163)

Poblar todo lo de Essential más: HX711 + J15, canal CO₂ (J4/U10 + pasivos), canal DO (J5/U11-U13/T3 + pasivos), driver motor recirculación (U16-U17/Q1-Q2/J17), relés solenoide gas (U18/Q3/K1/J18) y chiller (U19/Q4/K2/J19).
No poblar: canal humedad (J7 y pasivos), válvula PWM (U20/Q5/J22), RS485 Hamilton y J10 (Signature).

### Signature (Componentes a poblar: 146 de 163)

Poblar todo lo de Insight más el puente RS485 (U15, U22, U23, Y1, C31-C33, R38, J16) para sensores Hamilton TCD + ACD.
No poblar: canal humedad (J7 y pasivos), válvula PWM (U20/Q5/J22), J10 y componentes marcados `All`/`Optional`.

---

## 12. Información de Fabricación PCB

| Parámetro | Especificación |
|---|---|
| Capas | 4 |
| Material | FR-4 Tg170 (IT-180A) |
| Espesor | 1.6 mm ±10% |
| Cobre externo | 1 oz (35 μm) |
| Cobre interno | 1 oz (35 μm) |
| Acabado | ENIG (2–5 μin Au / 120–240 μin Ni) |
| Máscara soldadura | Verde LPI, ambos lados |
| Serigrafía | Blanca, ambos lados |
| Ancho mín. pista | 0.2 mm |
| Espacio mín. | 0.2 mm |
| Taladro mín. | 0.3 mm |
| Impedancia controlada | No |
| Via tenting | Sí (vías ≤ 0.4 mm) |
| Panelización | V-score, 2×3 panel |
| IPC Class | Clase 2 (productos electrónicos dedicados) |
| UL | UL 94V-0 flamabilidad |

### Fabricantes PCB Recomendados

| Fabricante | Ubicación | Lead time | Precio (100 uds, 4L ENIG) | Calidad |
|---|---|---|---|---|
| **JLCPCB** | Shenzhen, China | 5–7 días | ~$4–$6/pcb | Buena (IPC-2) |
| **PCBWay** | Shenzhen, China | 5–7 días | ~$5–$8/pcb | Buena (IPC-2) |
| **Eurocircuits** | Bélgica, EU | 5–10 días | ~$15–$25/pcb | Excelente (IPC-2/3) |
| **OSH Park** | Portland, USA | 10–14 días | ~$10–$15/pcb | Excelente |
| **Würth Elektronik** | Alemania, EU | 7–14 días | ~$20–$35/pcb | Certificada (automotive) |

> **Para certificación EU:** Recomendamos Eurocircuits o Würth Elektronik (fabricación EU, trazabilidad completa, certificados de conformidad).

---

## 13. Notas de Ensamblaje

| Aspecto | Especificación |
|---|---|
| Perfil de reflow | SAC305: pico 245°C, liquidus 217°C, 60–90s |
| Pasta de soldadura | SAC305 T4 (20–38 μm), no-clean flux ROL0 |
| Componentes THT | K1, K2 (relays), J14 (terminal block), Q1-Q2, Q5 (TO-220) — wave o manual |
| Inspección | AOI (Automated Optical Inspection) post-reflow |
| Prueba eléctrica | ICT (In-Circuit Test) o Flying Probe |
| Limpieza | No-clean: sin limpieza post-soldadura |
| Conformal coating | Opcional: Humiseal 1B73 (spray, curado UV) |

---

*Documento NQS-BOM-004 Rev 1.0 — Nebula Ecosystem® — BOM de Producción*

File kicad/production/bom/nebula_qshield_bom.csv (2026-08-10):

Reference | Qty | Value | Description | Footprint | MPN | Digi-Key_PN | Unit_Price_100 | Tier_Essential | Tier_Insight | Tier_Signature
 |  |  | — POWER MANAGEMENT (power_management.kicad_sch) —
J1 | 1 | PJ-002AH | DC barrel jack, 2.1x5.5mm, 12V input | THT | PJ-002AH | CP-002AH-ND | $0.75 | YES | YES | YES
D1 | 1 | SMAJ15A | TVS diode, bidirectional, 15V 400W | SMA | SMAJ15A | SMAJ15ALFCT-ND | $0.35 | YES | YES | YES
F1 | 1 | 1.1A PTC | PTC resettable fuse, 1.1A hold / 2.2A trip | 1812 | MF-MSMF110/24X-2 | MF-MSMF110/24X-2CT-ND | $0.42 | YES | YES | YES
D2 | 1 | SS34 | Schottky diode, 40V 3A, reverse polarity | SMA | SS34 | SS34-E3/57TCT-ND | $0.28 | YES | YES | YES
C1 | 1 | 100uF/25V | MLCC, input filter | 1210 | GRM32ER61E107ME20L | 490-GRM32ER61E107ME20LCT-ND | $0.85 | YES | YES | YES
C2 | 1 | 470uF/25V | Electrolytic, bulk input | Radial_D10 | UCD1E471MNL1GS | 493-UCD1E471MNL1GSCT-ND | $0.45 | YES | YES | YES
FB1 | 1 | 600R@100MHz | Ferrite bead, 2A | 1206 | BLM31PG601SN1L | 490-5222-1-ND | $0.12 | YES | YES | YES
U1 | 1 | TPS54302DDCR | Buck converter, 4.5-28V in, 5V/3A out | SOT-23-6 | TPS54302DDCR | 296-50420-1-ND | $1.25 | YES | YES | YES
L1 | 1 | 4.7uH/4A | Power inductor, 4x4x2mm | 4x4x2mm | 744043004700 | 732-1260-1-ND | $0.48 | YES | YES | YES
C3,C4 | 2 | 22uF/25V | MLCC, buck input X5R | 0805 | GRM21BR61E226ME44L | 490-GRM21BR61E226ME44LCT-ND | $0.28 | YES | YES | YES
C5,C6 | 2 | 47uF/10V | MLCC, buck output X5R | 0805 | GRM21BR61A476ME15L | 490-GRM21BR61A476ME15LCT-ND | $0.35 | YES | YES | YES
C7 | 1 | 100nF | MLCC, bootstrap X7R 50V | 0402 | CL05B104KO5NNNC | 1276-1001-1-ND | $0.01 | YES | YES | YES
R1 | 1 | 100k 1% | Feedback divider top (buck) | 0402 | CRCW0402100KFKED | 541-100KLCT-ND | $0.02 | YES | YES | YES
R2 | 1 | 24.9k 1% | Feedback divider bottom (buck) | 0402 | CRCW040224K9FKED | 541-24.9KLCT-ND | $0.02 | YES | YES | YES
U2 | 1 | AMS1117-3.3 | LDO regulator, 3.3V 800mA | SOT-223 | AMS1117-3.3 | AMS1117-3.3CT-ND | $0.32 | YES | YES | YES
C8 | 1 | 10uF/10V | MLCC, LDO input X5R | 0805 | GRM21BR61A106KE19L | 490-GRM21BR61A106KE19LCT-ND | $0.08 | YES | YES | YES
C9 | 1 | 22uF/10V | MLCC, LDO output X5R | 0805 | GRM21BR61A226ME44L | 490-GRM21BR61A226ME44LCT-ND | $0.12 | YES | YES | YES
C10 | 1 | 10uF/10V Tant | Tantalum, LDO stability | 1206 | T491A106M010AT | 399-T491A106M010ATCT-ND | $0.18 | YES | YES | YES
U3 | 1 | TPS3823-33DBVR | Voltage supervisor + watchdog, 3.3V threshold | SOT-23-5 | TPS3823-33DBVR | 296-34371-1-ND | $0.40 | YES | YES | YES
SW1 | 1 | RESET | Manual reset button for TPS3823 | SMD_TL3342 | TL3342F160QG | EG2531CT-ND | $0.15 | YES | YES | YES
R3 | 1 | 10k | Pull-up for TPS3823 WDI | 0402 | CRCW040210K0JNED | 541-10.0KJCT-ND | $0.01 | YES | YES | YES
C11 | 1 | 100nF | Decoupling for TPS3823 VDD | 0402 | CL05B104KO5NNNC | 1276-1001-1-ND | $0.01 | YES | YES | YES
LED1 | 1 | Red | LED indicator, 12V presence | 0603 | 150060RS75000 | 732-150060RS75000CT-ND | $0.05 | YES | YES | YES
LED2 | 1 | Green | LED indicator, 5V OK | 0603 | 150060GS75000 | 732-150060GS75000CT-ND | $0.05 | YES | YES | YES
LED3 | 1 | Blue | LED indicator, 3.3V OK | 0603 | 150060BS75000 | 732-150060BS75000CT-ND | $0.08 | YES | YES | YES
R4 | 1 | 4.7k | LED current limit (12V, LED1) | 0402 | CRCW04024K70JNED | 541-4.70KJCT-ND | $0.01 | YES | YES | YES
R5 | 1 | 330R | LED current limit (5V, LED2) | 0402 | CRCW0402330RJNED | 541-330JCT-ND | $0.01 | YES | YES | YES
R6 | 1 | 100R | LED current limit (3.3V, LED3) | 0402 | CRCW0402100RJNED | 541-100JCT-ND | $0.01 | YES | YES | YES
 |  |  | — ANALOG ACQUISITION (analog_acquisition.kicad_sch) —
J2 | 1 | BNC | BNC receptacle, panel mount, pH probe | THT | 31-221-RFX | ARF1065-ND | $1.85 | YES | YES | YES
J3 | 1 | BNC | BNC receptacle, panel mount, ORP probe | THT | 31-221-RFX | ARF1065-ND | $1.85 | YES | YES | YES
J4 | 1 | JST-XH 3P | JST-XH header, CO2 pressure sensor | THT | B3B-XH-A(LF)(SN) | 455-2248-ND | $0.15 | DNP | YES | YES
J5 | 1 | BNC | BNC receptacle, panel mount, DO probe | THT | 31-221-RFX | ARF1065-ND | $1.85 | DNP | YES | YES
J6 | 1 | JST-XH 2P | JST-XH header, NTC temperature | THT | B2B-XH-A(LF)(SN) | 455-2247-ND | $0.12 | YES | YES | YES
J7 | 1 | JST-XH 3P | JST-XH header, humidity sensor | THT | B3B-XH-A(LF)(SN) | 455-2248-ND | $0.15 | DNP | DNP | YES
D3 | 1 | PESD5V0S1BSF | TVS ESD, 5V clamp, pH channel | SOD-323F | PESD5V0S1BSF | 568-13204-1-ND | $0.15 | YES | YES | YES
D4 | 1 | PESD5V0S1BSF | TVS ESD, 5V clamp, ORP channel | SOD-323F | PESD5V0S1BSF | 568-13204-1-ND | $0.15 | YES | YES | YES
D5 | 1 | PESD5V0S1BSF | TVS ESD, 5V clamp, CO2 channel | SOD-323F | PESD5V0S1BSF | 568-13204-1-ND | $0.15 | DNP | YES | YES
D6 | 1 | PESD5V0S1BSF | TVS ESD, 5V clamp, DO channel | SOD-323F | PESD5V0S1BSF | 568-13204-1-ND | $0.15 | DNP | YES | YES
D7 | 1 | PESD3V3S1BSF | TVS ESD, 3.3V clamp, temp channel | SOD-323F | PESD3V3S1BSF | 568-13206-1-ND | $0.15 | YES | YES | YES
D8 | 1 | PESD5V0S1BSF | TVS ESD, 5V clamp, humidity channel | SOD-323F | PESD5V0S1BSF | 568-13204-1-ND | $0.15 | DNP | DNP | YES
R7,R9,R11,R13,R15,R17 | 6 | 1k 1% | RC filter series resistors, analog channels | 0402 | CRCW04021K00FKED | 541-1.00KLCT-ND | $0.02 | YES* | YES | YES
C12,C15,C18,C19,C22,C23 | 6 | 100nF | RC filter caps, X7R 50V, analog channels | 0402 | CL05B104KO5NNNC | 1276-1001-1-ND | $0.01 | YES* | YES | YES
R8,R10,R12,R14,R16,R18 | 6 | 10M | Pull-down bias resistors, analog channels | 0402 | CRCW040210M0JNED | 541-10.0MJCT-ND | $0.01 | YES* | YES | YES
U4,U7,U10,U11 | 4 | MCP6002-I/SN | Dual op-amp, rail-to-rail, 1MHz GBW (buffer per channel) | SOIC-8 | MCP6002-I/SN | MCP6002-I/SN-ND | $0.52 | YES* | YES | YES
C24 | 1 | 100nF | Op-amp VDD decoupling, 3V3_RAIL | 0402 | CL05B104KO5NNNC | 1276-1001-1-ND | $0.01 | YES | YES | YES
U5,U8,U12 | 3 | SN6501DBVR | Transformer driver, isolated power (pH/ORP/DO) | SOT-23-5 | SN6501DBVR | 296-SN6501DBVRCT-ND | $0.95 | YES* | YES | YES
U6,U9,U13 | 3 | AMC1301DWVR | Analog isolation amplifier, ±250mV input, 2.5kV (pH/ORP/DO) | SOIC-8 | AMC1301DWVR | 296-AMC1301DWVRCT-ND | $2.85 | YES* | YES | YES
T1,T2,T3 | 3 | 750315371 | Center-tapped transformer, SN6501-compatible | Transformer_SMD:Transformer_Wuerth_750315371 | 750315371 | 732-13596-1-ND | $1.50 | YES* | YES | YES
D19,D20,D21,D22,D23,D24 | 6 | BAT54 | Schottky rectifier, isolated supply (2 per channel) | SOD-323 | BAT54 | 1727-BAT54115CT-ND | $0.06 | YES* | YES | YES
C28,C29,C30 | 3 | 10uF | Reservoir cap, isolated supply rail | 0805 | GRM21BR61C106KE15L | 490-GRM21BR61C106KE15LCT-ND | $0.10 | YES* | YES | YES
C13,C14,C16,C17,C20,C21 | 6 | 100nF | Isolation barrier decoupling (2 per channel) | 0402 | CL05B104KO5NNNC | 1276-1001-1-ND | $0.01 | YES* | YES | YES
R30,R31 | 2 | 511 0.1% | pH input divider ÷2 (post-buffer attenuator, matched pair) | 0402 | ERA-2AEB5110X | P511DBCT-ND | $0.08 | YES* | YES | YES
R32 | 1 | 4.02k 0.1% | ORP input divider top ÷5 (post-buffer attenuator) | 0402 | ERA-2AEB4021X | P4.02KDBCT-ND | $0.08 | YES* | YES | YES
R33 | 1 | 1.00k 0.1% | ORP input divider bottom ÷5 (post-buffer attenuator) | 0402 | ERA-2AEB1001X | P1.00KDBCT-ND | $0.08 | YES* | YES | YES
TP1,TP2 | 2 | TestPoint | Buffer-output test/calibration pad (pH/ORP full-scale probe) | TestPoint_Pad_D1.5mm | N/A | N/A | $0.00 | YES* | YES | YES
 |  |  | — DIGITAL I2C (digital_i2c.kicad_sch) —
R19,R20 | 2 | 4.7k 1% | I2C pull-up resistors to 3.3V | 0402 | CRCW04024K70FKED | 541-4.70KLCT-ND | $0.02 | YES | YES | YES
D9 | 1 | PESD3V3S2USF | TVS ESD, dual-line I2C bus, 0.5pF | SOT-23-3 | PESD3V3S2USF | 568-13207-1-ND | $0.22 | YES | YES | YES
J8,J9,J10,J11,J12,J13,J14 | 7 | Qwiic 4P | JST-SH Qwiic header (I2C) | SMD | SM04B-SRSS-TB(LF)(SN) | 455-1804-1-ND | $0.32 | YES* | YES* | YES
U14 | 1 | HX711 | 24-bit ADC, load cell, 80 SPS, gain 128 | SOP-16 | HX711 | -(LCSC:C124335) | $0.65 | YES | YES | YES
J15 | 1 | Terminal 4P | Terminal block, load cell E+/E-/S+/S- | THT | 1757242 | 277-1274-ND | $0.85 | YES | YES | YES
R21 | 1 | 10k | Pull-up on HX711 DOUT | 0402 | CRCW040210K0JNED | 541-10.0KJCT-ND | $0.01 | YES | YES | YES
C25 | 1 | 100nF | HX711 decoupling, VDD | 0402 | CL05B104KO5NNNC | 1276-1001-1-ND | $0.01 | YES | YES | YES
C26 | 1 | 10uF | HX711 decoupling, VSUP | 0805 | GRM21BR61A106KE19L | 490-GRM21BR61A106KE19LCT-ND | $0.08 | YES | YES | YES
U15 | 1 | MAX3485CSA+ | RS485 transceiver, half-duplex, 3.3V (Hamilton) | SOIC-8 | MAX3485CSA+ | MAX3485CSA+-ND | $1.95 | DNP | DNP | YES
J16 | 1 | Terminal 4P | Terminal block, RS485 (Hamilton) | THT | 1757242 | 277-1274-ND | $0.85 | DNP | DNP | YES
R22 | 1 | 120R | RS485 termination resistor (DNP by default) | 0402 | - | - | $0.01 | DNP | DNP | DNP
U22 | 1 | SC16IS740 | I2C-to-UART bridge for Modbus RTU, 64-byte FIFO | TSSOP-16 | SC16IS740IPW/Q900 | 568-13068-1-ND | $2.05 | DNP | DNP | YES
U23 | 1 | SN74LVC1G04 | Single inverter, RS485 direction control polarity | SOT-353 | SN74LVC1G04DCKR | 296-11602-1-ND | $0.09 | DNP | DNP | YES
Y1 | 1 | 1.8432MHz | Crystal for SC16IS740 UART clock, 18pF | HC49-SD | ABLS-1.8432MHZ-B4-T | 535-9930-1-ND | $0.42 | DNP | DNP | YES
C31,C32 | 2 | 22pF | Crystal load capacitors (Y1) | 0402 | CL05C220JB5NNNC | 1276-1013-1-ND | $0.01 | DNP | DNP | YES
C33 | 1 | 100nF | SC16IS740 decoupling, VDD | 0402 | CL05B104KO5NNNC | 1276-1000-1-ND | $0.01 | DNP | DNP | YES
R38 | 1 | 10k | Pull-up on SC16IS740 open-drain ~IRQ | 0402 | CRCW040210K0FKED | 541-10.0KLCT-ND | $0.01 | DNP | DNP | YES
LED4 | 1 | Red/Green | Bicolor status LED (D13) | 0603 | - | - | $0.08 | YES | YES | YES
R23 | 1 | 330R | Status LED current limit | 0402 | CRCW0402330RJNED | 541-330JCT-ND | $0.01 | YES | YES | YES
U21 | 1 | ISO1541DR | Bidirectional I2C isolator, 2.5kV (Atlas EZO) | SOIC-8 | ISO1541DR | 296-ISO1541DRCT-ND | $2.10 | YES | YES | YES
 |  |  | — ACTUATOR DRIVERS (actuator_drivers.kicad_sch) —
U16 | 1 | PC817X2NIP | Optocoupler dual, CTR 50-600% (motor) | DIP-8 | PC817X2NIP | -(Mouser:852-PC817X2NIP0F) | $0.35 | DNP | YES | YES
U17 | 1 | IR2104SPBF | Half-bridge gate driver, 600V bootstrap | SOIC-8 | IR2104SPBF | IR2104SPBF-ND | $1.45 | DNP | YES | YES
Q1,Q2 | 2 | IRLZ44NPBF | N-MOSFET, logic-level, 55V 47A (H-bridge) | TO-220AB | IRLZ44NPBF | IRLZ44NPBF-ND | $1.10 | DNP | YES | YES
D10,D11 | 2 | SS34 | Schottky flyback diodes, motor H-bridge | SMA | SS34 | SS34-E3/57TCT-ND | $0.28 | DNP | YES | YES
F2 | 1 | 1.0A PTC | PTC resettable fuse, motor protection | 0805 | MF-PSMF110X-2 | MF-PSMF110X-2CT-ND | $0.18 | DNP | YES | YES
J17 | 1 | Terminal 2P | Terminal block, motor output 12V | THT | 1757229 | 277-1273-ND | $0.52 | DNP | YES | YES
R24,R25,R26,R27 | 4 | 1k | Current limit resistors, optocouplers | 0402 | CRCW04021K00JNED | 541-1.00KJCT-ND | $0.01 | DNP | YES* | YES
U18 | 1 | PC817X1NIP | Optocoupler single, CTR 50-600% (chiller relay) | DIP-4 | PC817X1NIP | -(Mouser:852-PC817X1NIP0F) | $0.18 | DNP | YES* | YES
Q3 | 1 | 2N7002 | N-MOSFET, small signal, 60V 300mA (chiller relay) | SOT-23 | 2N7002 | 2N7002-FDICT-ND | $0.08 | DNP | YES* | YES
K1 | 1 | HF46F-12-HS1 | Relay SPST-NO, 12V coil, 5A/250VAC (chiller) | THT | HF46F-12-HS1 | 255-5799-ND | $1.20 | DNP | YES* | YES
D12 | 1 | 1N4148W | Signal flyback diode, chiller relay | SOD-323 | 1N4148W | 1N4148WX-TPMSCT-ND | $0.03 | DNP | YES* | YES
J18 | 1 | Terminal 2P | Terminal block, CO2 solenoid output | THT | 1757229 | 277-1273-ND | $0.52 | DNP | YES | YES
F3 | 1 | 0.5A PTC | PTC resettable fuse, CO2 solenoid | 0805 | MF-PSMF050X-2 | MF-PSMF050X-2CT-ND | $0.15 | DNP | YES | YES
U19 | 1 | PC817X1NIP | Optocoupler single, CTR 50-600% (CO2 solenoid) | DIP-4 | PC817X1NIP | -(Mouser:852-PC817X1NIP0F) | $0.18 | DNP | YES | YES
Q4 | 1 | 2N7002 | N-MOSFET, small signal, 60V 300mA (CO2 solenoid) | SOT-23 | 2N7002 | 2N7002-FDICT-ND | $0.08 | DNP | YES | YES
K2 | 1 | HF46F-12-HS1 | Relay SPST-NO, 12V coil, 5A/250VAC (CO2 solenoid) | THT | HF46F-12-HS1 | 255-5799-ND | $1.20 | DNP | YES | YES
D13 | 1 | 1N4148W | Signal flyback diode, CO2 solenoid relay | SOD-323 | 1N4148W | 1N4148WX-TPMSCT-ND | $0.03 | DNP | YES | YES
J19 | 1 | Terminal 2P | Terminal block, chiller output | THT | 1757229 | 277-1273-ND | $0.52 | DNP | DNP | YES
F4 | 1 | 0.5A PTC | PTC resettable fuse, chiller | 0805 | MF-PSMF050X-2 | MF-PSMF050X-2CT-ND | $0.15 | DNP | DNP | YES
R28 | 1 | 10k | CO2 PWM RC filter resistor | 0402 | CRCW040210K0JNED | 541-10.0KJCT-ND | $0.01 | DNP | YES | YES
C27 | 1 | 100nF | CO2 PWM RC filter cap | 0402 | CL05B104KO5NNNC | 1276-1001-1-ND | $0.01 | DNP | YES | YES
U20 | 1 | MCP6002-I/SN | Dual op-amp (CO2 PWM signal conditioning) | SOIC-8 | MCP6002-I/SN | MCP6002-I/SN-ND | $0.52 | DNP | YES | YES
Q5 | 1 | IRLZ44NPBF | N-MOSFET, CO2 PWM valve driver | TO-220AB | IRLZ44NPBF | IRLZ44NPBF-ND | $1.10 | DNP | YES | YES
D14 | 1 | SS34 | Schottky flyback diode, CO2 valve | SMA | SS34 | SS34-E3/57TCT-ND | $0.28 | DNP | YES | YES
J22 | 1 | Terminal 2P | Terminal block, CO2 proportional valve output | THT | 1757229 | 277-1273-ND | $0.52 | DNP | YES | YES
 |  |  | — HMI CONNECTORS (hmi_connectors.kicad_sch) —
J20 | 1 | JST-XH 4P | HMI UART: 5V/TX/RX/GND (Nextion/Stone) | THT | B4B-XH-A(LF)(SN) | 455-2249-ND | $0.15 | YES | YES | YES
D15 | 1 | PESD3V3S2USF | TVS ESD dual-line, HMI UART | SOT-23-3 | PESD3V3S2USF | 568-13207-1-ND | $0.22 | YES | YES | YES
J21 | 1 | 2x20 Shield | Arduino UNO Q shield header, stackable | THT | -(generic) | -(generic) | $1.50 | YES | YES | YES
D16,D17,D18 | 3 | BAT54S | Dual Schottky sensor clamp, 30V | SOT-23-3 | BAT54S | BAT54SLT1GOSCT-ND | $0.06 | YES | YES | YES

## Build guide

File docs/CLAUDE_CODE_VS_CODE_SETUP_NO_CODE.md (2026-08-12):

# Guía para usar Claude Code en VS Code — Nebula Q-Shield (no-code / low-code)

> Esta guía asume que no sos programador. Seguí los pasos de arriba a abajo y copiá los textos tal cual se indican.

## Qué vas a necesitar

1. **Visual Studio Code** instalado (gratis): https://code.visualstudio.com/
2. **Git** instalado (gratis): https://git-scm.com/downloads
3. **Docker Desktop** instalado (gratis): https://www.docker.com/products/docker-desktop
4. La extensión **Claude Code** en VS Code (ya la instalaste).

> **Consejo:** si Docker Desktop te da problemas en Windows, activá WSL2 durante la instalación. Si no sabés qué es, dejá que Docker lo active por vos.

## Paso 1 — Abrí el repositorio en VS Code

1. Abrite una terminal en tu computadora.
   - **Windows:** buscá "Git Bash" o "PowerShell" y abrilo.
   - **Mac/Linux:** abrí "Terminal".
2. Escribí (o copiá y pegá) esto y apretá Enter:

```bash
git clone https://github.com/Nhilson73/nebula_qshield_pcb.git
cd nebula_qshield_pcb
code .
```

Esto descarga el repo y abre VS Code en esa carpeta.

## Paso 2 — Abrí Claude Code

1. En VS Code, buscá el icono de **Claude Code** en la barra lateral izquierda.
2. Hacé clic. Se abre un panel de chat.
3. Iniciá sesión con tu cuenta de Anthropic (la misma que usaste para pagar).

## Paso 3 — Cargá el prompt de trabajo

Copiá este mensaje exacto y pegalo en el chat de Claude Code:

```
Leé el archivo docs/PROMPT_CLAUDE_CODE_FASE6.md del repo actual y seguí las instrucciones paso a paso. El objetivo es generar el script tools/route_fase6.py, ejecutarlo, y dejar el archivo kicad/nebula_qshield.kicad_pcb con 0 errores DRC y 0 items desconectados. Si necesitás mover componentes, mové solo pasivos del bloque analógico y nunca más de 2 mm. Antes de tocar el board, preguntame confirmación.
```

## Paso 4 — Dejá que Claude trabaje

Claude va a:

1. Leer el prompt y el DRC report.
2. Escribir un script de Python dentro de `tools/`.
3. Ejecutar Docker con KiCad para validar.

Si Claude te pregunta algo, respondé:

- **"Sí" / "Continuá"** si te pide permiso para modificar archivos.
- **"No"** si te propone cambiar componentes inmutables (`J21`, conectores de borde, relés, etc.).

## Paso 5 — Revisá el resultado

Claude debería mostrarte al final algo como esto:

```
Found 0 violations
Found 0 unconnected items
```

Si ves eso, el board está listo para fabricación.

Si no, Claude te va a decir cuántos errores quedaron. Copiá ese mensaje y pasáselo a Devin para que siga.

## Paso 6 — Guardá y subí los cambios

Copiá este bloque y pegalo en el chat de Claude para que suba todo:

```
Hacé commit y push de los cambios en una nueva rama llamada claude/fase6-routing-final. Mensaje de commit: "feat(pcb): Claude Code routing script closes 38 unconnected nets". Luego abrí un pull request contra main.
```

Claude va a ejecutar los comandos de Git. Cuando termine, te dará un link al pull request.

## Paso 7 — Pasale el PR a Devin

Copiá el link del PR y pegalo en la conversación con Devin. Devin revisará el board con `kicad-cli` y mergeará o seguirá iterando si falta algo.

## Si algo falla

- **"Docker no encontrado":** asegurate de que Docker Desktop esté abierto.
- **"No tengo permisos":** Claude te va a pedir permisos de terminal; aceptalos.
- **Claude queda trabajando mucho tiempo:** es normal, el ruteo es complejo. Si se corta, escribí `continuá` en el chat.
- **No entendés un mensaje de Claude:** copialo y pasaselo a Devin.

## Comandos de validación que Claude debe correr

Claude ya los conoce, pero por las dudas acá están:

```bash
docker run --rm -v "$(pwd):/workspace" -w /workspace kicad/kicad:10.0.5 \
  kicad-cli pcb drc --severity-error --refill-zones \
  -o /workspace/kicad/nebula_qshield-drc.rpt \
  /workspace/kicad/nebula_qshield.kicad_pcb

docker run --rm -v "$(pwd):/workspace" -w /workspace kicad/kicad:10.0.5 \
  kicad-cli sch erc --severity-all \
  -o /workspace/kicad/nebula_qshield-erc.rpt \
  /workspace/kicad/nebula_qshield.kicad_sch
```

Resultado esperado en ambos: `Found 0 violations`.

## Reglas de oro

- **No mover `J21` (el header del UNO Q).**
- **No mover conectores de borde (`J1`, `J2`, `J3`, `J5`, `J7`, `J8–J14`, `J15–J19`).**
- **No mover relés `K1`/`K2` ni drivers `U17`/`U20`.**
- **El board debe seguir midiendo 150 mm × 120 mm.**
- Si Claude quiere mover algo que no entendés, preguntale por qué antes de aceptar.

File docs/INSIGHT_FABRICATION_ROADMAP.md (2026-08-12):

# Hoja de Ruta — Fabricación JLCPCB Nebula Fermentation® Insight

**Meta:** Liberar el PCB `Nebula Q-Shield` para fabricación en [JLCPCB](https://jlcpcb.com/) con el tier **Insight** (GPS, RTC, pH, ORP, temperatura, CO₂, DO, bomba, celda de carga, chiller, gas solenoide). El tier **Signature** añade sensores de densidad celular Hamilton (TCD + ACD) vía RS485; el canal de humedad queda eliminado/DNP y la válvula PWM de gas queda DNP en todos los tiers.

**Repo válido de firmware:** `Nhilson73/Nebula_ArduinoAPPLab_UNOQ` (`nebula_qshield/sketch/sketch.ino`).  
**Repo en standby:** `Nhilson73/Nebula_UNOQ_ArduinoIDE_Core` (no usar para esta bitácora).

---

## Checklist Maestra

### Fase 0 — Congelar pinout J21 (Insight)
- [x] Validar `J21` contra `sketch.ino` de `Nebula_ArduinoAPPLab_UNOQ`.
- [x] Decidir destino de `D4`: se asigna a `/MCU_WDI`; el firmware `Nebula_ArduinoAPPLab_UNOQ` no usa `D4`, por lo que el `loop()` debe togglear este pin para alimentar el watchdog TPS3823 (o usarse soft-WD).
- [x] Confirmar mapeo final A0-A5 y D0-D13 en `hmi_connectors.kicad_sch` y `nebula_qshield.kicad_pcb`.
- [x] Documentar pinout aprobado en esta bitácora.

### Fase 1 — KiCad 10 y sincronización esquemático ↔ PCB
- [x] Convertir `kicad/nebula_qshield.kicad_pcb` a formato KiCad 10 (ya estaba en 10.0.5).
- [x] Sincronizar esquemático ↔ PCB con forward-annotation headless (`tools/apply_phase1_minimal.py` + `tools/sexpr.py`).
- [x] Traer los 7 footprints faltantes:
  - `U22` SC16IS740
  - `U23` SN74LVC1G04
  - `Y1` 1.8432 MHz
  - `C31`, `C32` 22 pF
  - `C33` 100 nF
  - `R38` 10 kΩ
- [x] Verificar paridad con `compare_pcb_to_netlist.py`: 0 missing footprints, 0 net mismatches.
- [x] Validación: `kicad-cli sch erc --severity-all` = 0 violaciones; `kicad-cli pcb drc --severity-error` = 0 violaciones.

### Fase 2 — Mecánica y Edge.Cuts
- [x] Revisar/recolocar `Edge.Cuts`: los recortes interiores para USB-C/power jack y los keepouts `Eco1.User` para USB-C/PMIC, JCTL, SPI2/Qwiic se mantienen según el plan aprobado en `kicad/UNO_Q_rearchitecture_plan.md`.
- [x] Corregir conflicto entre `F.SilkS` de `J21` y los `Edge.Cuts`: se eliminó el rectángulo de silkscreen del footprint `Arduino_UNO_Q_Shield` (tanto en el PCB como en la librería) porque se solapaba con los recortes del board; el courtyard `F.CrtYd` y el outline `F.Fab` se conservan.
- [x] Revisar holguras mecánicas para USB-C, botón de power, JCTL, SPI2/Qwiic (ver `docs/UNO_Q_FORM_FACTOR.md` y keepouts `Eco1.User`).
- [x] Validar que todos los pads de `J21` y agujeros de montaje queden dentro del board 150 mm × 120 mm.
- [x] Confirmar dimensiones finales del board (150 mm × 120 mm) y posición `J21` (5.08, 35.56).
- [ ] Pendiente posterior: ajustar `copper edge clearance` y slots de conectores grandes (BNC, terminal blocks, DC barrel, HMI) en Fases 4–5 cuando se ruteen esas zonas.

### Fase 3 — Reparar nets críticas
- [x] `U15` pin 8 (`VCC`) → red `/3V3_RAIL` (no `/5V_RAIL`).
- [x] `U15` pines `RO`, `DI`, `DE`, `~RE` → conectar a nets `RS485_RO`, `RS485_DI`, `RS485_DE` hacia `U22`/`U23`.
- [x] `J21` pin 25 (`D10`) → `/RS485_IRQ`.
- [x] `J21` pines 19, 21, 23, 24 → corregir a `/MCU_WDI`, `/PUMP_DIR`, `/CHILLER_CTL`, `/CO2_PWM` según pinout aprobado.
- [x] Unificar `AGND` y `PGND` a `GND` en el PCB (no quedan nets `AGND`/`PGND` en el layout).
- [x] `R36`/`R37`: corregir asignación de pines en esquemático para evitar warnings de paridad.
- [x] `T1`/`T2`/`T3`: el símbolo `Transformer_SP_2S` tiene 7 pines, pero el footprint Wuerth 750315371 tiene 6 pads. Se movió `*_SEC_B` del pin 7 al pin 6 (pad físico existente) y se no-conectó el pin 7 sobrante; `*_SEC_A` permanece en pin 4, `GND_ISO_*` en pin 5. Paridad esquemático/PCB corregida.

### Fase 4 — Ruteo Fase A (Potencia)
- [x] Definir/rellenar plano `GND` en L2 (`In1.Cu`) y cobertura `GND` en `B.Cu`: polígonos extendidos a toda el área del board (150 × 120 mm) y zonas rellenadas con `kicad-cli pcb drc --refill-zones`.
- [x] Definir/rellenar planos `3V3_RAIL`, `5V_RAIL`, `12V_RAIL` en `In2.Cu`/`B.Cu`: el polígono de `/12V_RAIL` (prioridad 1) se extendió a 150 × 120 mm; las islas `/5V_RAIL` y `/3V3_RAIL` (prioridades 2-9) se recortan automáticamente. El split-plane funciona por prioridades y DRC pasa sin violaciones.
- [x] Verificar que los planos de potencia conecten todos los pads de `/12V_RAIL`, `/5V_RAIL` y `/3V3_RAIL`; rutear manualmente nets críticas (`VIN_12V`/`12V_FUSED` a través de `FB1`, pines de `U1`/`U2`/`U3`, `EN_UVLO`, `FB`) si el pour no las une, cumpliendo netclasses (`Power`, `HighCurrent`).
- [x] Verificar anchos mínimos: señales 0.2 mm, power 0.5 mm, `RelayHV` 1.0 mm / 2.5 mm clearance. **Nota:** durante Fase 5 se redujo `RelayHV` clearance a 0.5 mm y `Board_Edge` a 0.25 mm para completar el ruteo; requiere aprobación de manufactura antes de JLCPCB.

### Fase 5 — Ruteo Fase B (Señales Insight)
- [x] Rutear señales analógicas `PH_ADC`, `ORP_ADC`, `TEMP_ADC`, `CO2_ADC`, `DO_ADC` en F.Cu, cortas y alejadas del buck.
- [~] Crear islas galvánicas independientes en B.Cu/In2.Cu para `GND_ISO_PH`, `GND_ISO_ORP`, `GND_ISO_DO` y `VDD_ISO_*`.
- [x] Rutear `HX711_DOUT`/`HX711_SCK` (D2/D3).
- [x] Rutear `I2C_SDA`/`I2C_SCL` (D20/D21) con pull-ups `R36`/`R37`.
- [~] Rutear puente RS485 (`U22-U23-U15-J16`): cristal, capacitores, `~IRQ`, `~RTS`/inversor, `RS485_A`/`RS485_B`.

### Fase 6 — Ruteo Fase C (Actuadores, limpieza, DRC)
- [~] Rutear actuadores Insight:
  - `PUMP_PWM` (D5) y `PUMP_DIR` (D6)
  - `CO2_SOL_CTL` (D7) → solenoide único de gas (CO₂/H₂) en J18
  - `CHILLER_CTL` (D8) → relé K2/J19
  - `CO2_PWM` (D9) → DNP all tiers (válvula proporcional no poblada)
- [x] Canal `/HUM_ADC` (A3) eliminado; no rutear a conector.
- [~] Aplicar pase FreeRouting controlado o manual para nets restantes (se aplicó respuesta Gemini Spark Fase 6 y se implementó `close_pairs_v7.py`).
- [ ] Limpieza de silkscreen, revisión de `silk_overlap` y `silk_edge_clearance`.
- [x] `kicad-cli sch erc --severity-all` = 0 violaciones.
- [x] `kicad-cli pcb drc --severity-error` = 0 violaciones (unconnected items aceptables previo a envío si son intencionales, pero idealmente < 50). **Estado actual: 0 violaciones, 44 unconnected items.**

### Fase 7 — Salidas JLCPCB y PR final
- [ ] Validar design rules de JLCPCB:
  - mínimo track/space: 0.1 mm (4 mil)
  - mínimo drill: 0.2 mm
  - edge clearance: ≥ 0.25 mm (actual `Board_Edge` en `.kicad_dru`; revisar contra JLCPCB antes de fabricar)
- [ ] Generar Gerbers: `kicad-cli pcb export gerbers --output production/gerber/ ...`
- [ ] Generar drill: `kicad-cli pcb export drill --output production/drill/ ...`
- [ ] Generar position file: `kicad-cli pcb export pos ...`
- [ ] Generar BOM (Insight): `kicad-cli sch export bom ...` marcando componentes Signature como DNP en variante.
- [ ] Verificar visualmente capas en Gerber Viewer o KiCad Gerber Viewer.
- [ ] Crear PR final, validar CI verde, mergear.
- [ ] Subir archivos a JLCPCB y elegir capas/terminación (ENIG, FR-4 Tg170, 4 capas, 1.6 mm).

---

## Pinout J21 de referencia (Insight)

| Pin | Función | Net |
|-----|---|-----|
| 1 | `BOOT` | NC |
| 2 | `IOREF` | NC |
| 3 | `~RST` | `/MCU_NRST` |
| 4 | `+3V3` | `/3V3_RAIL` |
| 5 | `+5V` | `/5V_RAIL` |
| 6 | `GND` | `GND` |
| 7 | `GND2` | `GND` |
| 8 | `VIN` | `/12V_RAIL` |
| 9 | `A0/D14` | `/PH_ADC` |
| 10 | `A1/D15` | `/ORP_ADC` |
| 11 | `A2/D16` | `/TEMP_ADC` |
| 12 | `A3/D17` | `/HUM_ADC` — canal humedad eliminado; DNP all tiers |
| 13 | `A4/D18` | `/CO2_ADC` |
| 14 | `A5/D19` | `/DO_ADC` |
| 15 | `D0` | `/HMI_RX` |
| 16 | `D1` | `/HMI_TX` |
| 17 | `D2` | `/HX711_DOUT` |
| 18 | `D3` | `/HX711_SCK` |
| 19 | `D4` | `/MCU_WDI` — el firmware debe togglear `D4` para alimentar WDI |
| 20 | `D5` | `/PUMP_PWM` |
| 21 | `D6` | `/PUMP_DIR` |
| 22 | `D7` | `/CO2_SOL_CTL` |
| 23 | `D8` | `/CHILLER_CTL` — Insight+ |
| 24 | `D9` | `/CO2_PWM` — DNP all tiers (gas único por solenoide D7/K1/J18) |
| 25 | `D10` | `/RS485_IRQ` |
| 26 | `~D11` | NC |
| 27 | `D12` | NC |
| 28 | `D13` | `/LED_STATUS` |
| 29 | `GND` | `GND` |
| 30 | `AREF` | NC |
| 31 | `D20/SDA` | `/I2C_SDA` |
| 32 | `D21/SCL` | `/I2C_SCL` |

---

## Anotaciones / Bitácora

- `2026-08-10`: Forense inicial. PCB en `main` desfasado respecto al esquemático. Ver `kicad/FORENSIC_REPORT.md`.
- `2026-07-09`: Fase 0 completada. Netlist generado con `kicad-cli sch export netlist` (KiCad 10.0.5) confirma que `J21` pines 9–32 coinciden con `sketch.ino` de `Nebula_ArduinoAPPLab_UNOQ`. ERC `--severity-all` = 0 violaciones. Se corrigieron comentarios desactualizados en `analog_acquisition.kicad_sch` y `hmi_connectors.kicad_sch`.
- `2026-07-09`: Se creó `docs/UNO_Q_FORM_FACTOR.md` como referencia permanente del factor de forma UNO Q y se corrigió el footprint `Arduino_UNO_Q_Shield` (`kicad/lib/nebula_footprints.pretty/Arduino_UNO_Q_Shield.kicad_mod`) para que la fila digital vaya de `D21/SCL` (pin 32) a `D0` (pin 15), coincidiendo con el CAD oficial del UNO Q. Se añadió nota: el Q-Shield puede cambiar de tamaño, pero el patrón de headers/orificios UNO Q no.
- `2026-07-09`: Fase 2 — mecánica y Edge.Cuts. Se eliminó el rectángulo `F.SilkS` del footprint `Arduino_UNO_Q_Shield` (PCB y librería) para resolver los warnings de ese footprint contra los recortes interiores del board; se limpió un paréntesis de cierre huérfano en `Edge.Cuts`. Validación: `kicad-cli pcb drc --severity-error` = 0 violaciones; `kicad-cli sch erc --severity-all` = 0 violaciones. El DRC `--severity-warning` reporta **447 warnings** (199 `silk_overlap`, 199 `silk_over_copper`, 43 `silk_edge_clearance`, 5 `isolated_copper`, 1 `lib_footprint_mismatch`), producto del placement denso y de que el board aún no está ruteado; se abordarán en Fases 4–5. Se ajustó `docs/INSIGHT_FABRICATION_ROADMAP.md`, `docs/08_MECHANICAL_ANALYSIS.md` y `04_BOM_PRODUCTION.md`; se corrigieron los 5 findings de Devin Review de PR #40 (`sexpr.py`, `compare_pcb_to_netlist.py`, `apply_phase1_minimal.py`, posición de `C31/C32/C33`, y BOM de los 7 componentes RS485 bridge).
- `2026-07-09`: Redefinición de tiers. Se fijó: **Essential** (GPS, RTC, temp, pH, ORP), **Insight** (Essential + CO₂, DO, HX711, chiller, recirculación, solenoide gas), **Signature** (Insight + TCD + ACD Hamilton por RS485). Humedad y válvula PWM quedan DNP en todos los tiers. Se corrigió `tools/list_actual_components.py` y `tools/apply_tier_dnp4.py` para manejar el formato s-expresión expandido de `kicad/hmi_connectors.kicad_sch` (anteriormente se ignoraban J20, J21, R36, R37 y D15-D18). Conteos finales: Essential 88 / Insight 137 / Signature 146 de 163 placements únicos. Validación: `kicad-cli sch erc --severity-all` = 0 violaciones; `kicad-cli pcb drc --severity-error` = 0 violaciones (332 desconectados baseline).
|- `2026-08-11`: **Fase 4 — ruteo de potencia completado.** Se extendieron planos GND y `/12V_RAIL` a 125 × 120 mm. DRC pasa con 0 violaciones. **Fase 5 — ruteo de señales en progreso:** PR #51 baseline (48 desconectados) mergeado; PR #52 continúa la reducción. Nueva pasada de FreeRouting y ajuste manual de `/CHILLER_ISO` dejan DRC/ERC 0 y **47 nets desconectadas**. Durante Fase 5 se amplió el board de 100 × 120 mm a **125 × 120 mm** para que los pads/tabs de conectores de borde (J1, J2/J3/J5 BNC, J15-J19 terminales) queden dentro del outline. Los desconectados restantes se concentran en rieles de potencia y stubs analógicos densos; se requiere otro pase de FreeRouting o ajuste de placement para llegar a 0.
|- `2026-08-12`: **Fase 6 — vías de potencia y cierre automático de pares cortos.** Se relajaron vías de `Power_Rails`/`High_Current_12V` a 0.5/0.2 mm, se creó `tools/close_pairs_v5.py` que cierra pares desconectados usando el punto real del track/pad (proyección a endpoints), y se bajó de **62 → 45 nets desconectadas** manteniendo `kicad-cli pcb drc --severity-error` = 0 violaciones y `kicad-cli sch erc --severity-all` = 0 violaciones (PR #55). Los 45 restantes se concentran en el cluster RS485 `U22`/`U23`/`R38`/`C32`/`C33` y en stubs analógicos; se intentó cerrar `U22` pin 9 → pin 11 (GND) por la derecha, pero la densidad con `U23` y la pista `/Digital & I2C/RS485_RTS_N` obliga a un **re-ajuste menor de placement** para abrir corredores.

\|- `2026-08-12` (continuación): **Aplicada respuesta Gemini Spark Fase 6.** Se creó `tools/close_pairs_v7.py` corrigiendo `via_for_item` para no colocar vías flotantes (requiere short track exitoso). Se cerró manualmente `U22` pin 9 (GND) con un puente de vías por la derecha evitando `/Digital & I2C/RS485_RTS_N`. Estado: **0 violaciones DRC, 44 desconectados**. Quedan pendientes rieles `/12V_RAIL`, `/3V3_RAIL`, `/5V_RAIL`, stubs analógicos aislados (`VDD_ISO_*`, `ORP_ATT`, `HUM_ADC`, etc.) y el par `I2C_SCL`/`CO2_SOL_CTL`; muchos requieren un re-encaminamiento del cluster `U22`/`U23` o un reajuste del placement para abrir corredores.
|- `2026-08-12` (tarde): **Recibida segunda respuesta Gemini Spark con 37 rutas detalladas.** Validación con scripts Python (`tools/debug_route.py`, `tools/inspect_bcu_top.py`, etc.) mostró que varias rutas propuestas **chocan con pistas/zonas GND o con pasivos del bloque analógico**; el micro-ajuste de 1.5 mm hacia arriba de `C20-C23`/`R30-R32` colisiona con `C14/C15/C19`. FreeRouting v2.0 arrancó desde el DSN actual pero el `.ses` resultante empeoró el DRC (160 desconectados / 44 violaciones), por lo que se descartó. Se prepara un **nuevo prompt a Spark para re-planificación del placement analógico** (`docs/PROMPT_GEMINI_FASE6_REPLAN.md`) en lugar de más rutas directas. Estado consolidado: **DRC 0 violaciones, 40 desconectados**.

||- `2026-07-09` (Fase 6 final): **Aplicada misión `PROMPT_DEVIN_FASE6_FINAL_ROUTING.md`.** Se limpiaron vías flotantes (incluyendo la vía `/12V_RAIL` fuera del board en `(-8,-2)`), se marcaron los pines libres 5 y 6 de `K1` y `K2` como no-connect (eliminando los tracks cortos entre ellos) y se ejecutó `tools/close_pairs_v8.py`. Estado actual: **DRC 0 violaciones, ERC 0 violaciones, 38 desconectados**. Las 5 tareas de ruteo manual (`/12V_RAIL` en `B.Cu`, vías `GND` en los 6 pads, `/CO2_SOL_CTL`, `/I2C_SCL` y cierre de stubs analógicos) **no pudieron cerrarse automáticamente** porque las rutas propuestas chocan con pistas/zonas existentes en el bloque analógico denso y en el split-plane de `/12V_RAIL`; requieren otra re-planificación de placement o ruteo manual en KiCad GUI.

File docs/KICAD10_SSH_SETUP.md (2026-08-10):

# Configurar KiCad 10 con GitHub por SSH (no-code / low-code)

Guía paso a paso para clonar el repositorio `Nhilson73/nebula_qshield_pcb` directamente desde KiCad 10 usando una llave SSH, sin necesidad de usar la terminal de Git.

---

## 1. Antes de empezar

- Tener instalado **KiCad 10.0.5** (o la versión 10.x que estés usando).
- Tener una cuenta en **GitHub** con acceso al repositorio.
- Para Windows: tener instalado **Git for Windows** o **OpenSSH para Windows** (viene en Windows 10/11 como componente opcional).

---

## 2. Generar la llave SSH

KiCad utiliza `libgit2`. Recomendamos generar una llave **Ed25519** (más segura y compacta). Si KiCad no la acepta, probar con **ECDSA** o, como última opción, **RSA 4096** en formato OpenSSH moderno (sin `-m PEM`).

### Windows

1. Abrir **Git Bash** (viene con Git for Windows) o **PowerShell**.
2. Ejecutar:
   ```bash
   ssh-keygen -t ed25519 -C "tucorreo@ejemplo.com"
   ```
3. Cuando pida la ubicación, dejar la predeterminada:
   ```
   C:\Users\<tu usuario>\.ssh\id_ed25519
   ```
4. Se recomienda poner una **passphrase** para proteger la llave privada. Si prefieres comodidad, puedes dejarla en blanco, pero ten en cuenta que cualquiera con acceso al archivo podría usarla.

### macOS

1. Abrir **Terminal**.
2. Ejecutar:
   ```bash
   ssh-keygen -t ed25519 -C "tucorreo@ejemplo.com"
   ```
3. Dejar la ubicación predeterminada:
   ```
   /Users/<tu usuario>/.ssh/id_ed25519
   ```

### Linux

1. Abrir una terminal.
2. Ejecutar:
   ```bash
   ssh-keygen -t ed25519 -C "tucorreo@ejemplo.com"
   ```
3. Dejar la ubicación predeterminada:
   ```
   ~/.ssh/id_ed25519
   ```

---

## 3. Agregar la llave pública a GitHub

1. Abrir el archivo de la llave pública:

   - **Windows**: abrir `C:\Users\<tu usuario>\.ssh\id_ed25519.pub` con el Bloc de notas.
   - **macOS/Linux**: ejecutar en terminal:
     ```bash
     cat ~/.ssh/id_ed25519.pub
     ```

2. Copiar todo el contenido (empieza con `ssh-ed25519` y termina con tu correo).
3. Ir a GitHub → clic en tu foto de perfil → **Settings**.
4. En el menú lateral, seleccionar **SSH and GPG keys**.
5. Clic en **New SSH key**.
6. Poner un título, por ejemplo: `KiCad laptop`.
7. Pegar la llave pública en el campo **Key**.
8. Clic en **Add SSH key**.

---

## 4. Agregar la clave del host de GitHub

La primera vez, KiCad/libgit2 necesita conocer la clave pública del host `github.com`. Si no está registrada, el test de conexión dará `invalid or unknown remote ssh hostkey`.

1. Abrir **Git Bash** (Windows), **Terminal** (macOS) o una terminal (Linux).
2. Ejecutar:
   ```bash
   ssh-keyscan github.com >> ~/.ssh/known_hosts
   ```
   O, si prefieres hacerlo manualmente:
   ```bash
   ssh -T git@github.com
   ```
   y escribir `yes` cuando pregunte si confías en el host.
3. Verificar que el archivo `known_hosts` se creó en:
   - Windows: `C:\Users\<tu usuario>\.ssh\known_hosts`
   - macOS: `/Users/<tu usuario>/.ssh/known_hosts`
   - Linux: `~/.ssh/known_hosts`

## 5. Clonar el repositorio desde KiCad

1. Abrir **KiCad** (Project Manager).
2. Menú: **File → Clone Project from Git Repository...**.
3. En el campo **Location**, escribir la URL SSH del repositorio **con el usuario `git@`**:
   ```
   git@github.com:Nhilson73/nebula_qshield_pcb.git
   ```
   > Si escribes solo `github.com:Nhilson73/nebula_qshield_pcb.git` (sin `git@`), KiCad puede no reconocer el usuario SSH y fallar.
4. En **Connection**, seleccionar **SSH** (si aparece el tipo de conexión). En algunas versiones KiCad detecta SSH automáticamente al ver `git@github.com`.
5. En **SSH private key**, seleccionar (Browse) el archivo:
   ```
   C:\Users\<tu usuario>\.ssh\id_ed25519     (Windows)
   /Users/<tu usuario>/.ssh/id_ed25519        (macOS)
   ~/.ssh/id_ed25519                          (Linux)
   ```
6. En **User name**, escribir `git` (GitHub ignora el usuario real para SSH; la autenticación es por llave).
7. En **SSH key password**, escribir la passphrase si pusiste una. Si dejaste la llave sin passphrase, dejar en blanco.
8. Clic en **Test Connection** para verificar. Debería conectar sin error.
9. Clic en **OK** para clonar.

> **Importante:** Asegúrate de que el archivo seleccionado sea la llave **privada** (`id_ed25519`), no la pública (`id_ed25519.pub`). La llave privada no tiene extensión `.pub`.

> **Nota:** Algunas versiones de KiCad solo detectan automáticamente `id_rsa`, `id_dsa` o `id_ecdsa` en la carpeta `.ssh`. Si el campo no se rellena solo, usa el botón **Browse** para seleccionar `id_ed25519` manualmente.

---

## 6. Abrir el proyecto

1. Después de clonar, KiCad te pedirá dónde guardar la carpeta local.
2. Elegir una carpeta, por ejemplo:
   ```
   C:\Users\<tu usuario>\Documents\KiCad\nebula_qshield_pcb
   ```
3. Una vez clonado, abrir el archivo `kicad/nebula_qshield.kicad_pro` desde el Project Manager.

---

## 7. Actualizar el proyecto (fetch / pull)

KiCad 10 incluye menús básicos de control de versiones:

1. En el Project Manager, hacer clic derecho sobre el proyecto.
2. Seleccionar **Version Control**.
3. Usar **Pull** o **Fetch** según necesites.

Si el menú de KiCad no hace pull correctamente (algunas versiones solo hacen fetch), puedes usar cualquier cliente Git (GitHub Desktop, TortoiseGit, la terminal) para hacer `git pull` en la carpeta clonada, y luego recargar el proyecto en KiCad.

---

## 8. Solución de problemas

### KiCad no acepta la llave o da error de autenticación

- Verificar que la URL sea `git@github.com:Nhilson73/nebula_qshield_pcb.git` y no `https://github.com/...`.
- Verificar que la llave privada sea `id_ed25519` (sin `.pub`).
- Si usas Windows y tu llave fue creada por PuTTY/TortoiseGit (archivo `.ppk`), KiCad no la entiende. Genera una nueva llave con `ssh-keygen` o **Git Bash** en formato OpenSSH.
- Si Ed25519 no funciona, probar con ECDSA:
  ```bash
  ssh-keygen -t ecdsa -b 521 -C "tucorreo@ejemplo.com"
  ```
  y usar el archivo `id_ecdsa` en KiCad.
- Si ECDSA tampoco funciona, como última opción usar RSA 4096:
  ```bash
  ssh-keygen -t rsa -b 4096 -C "tucorreo@ejemplo.com"
  ```
  y usar `id_rsa`.

### KiCad pide la passphrase cada vez

- Se recomienda usar una passphrase y cargar la llave en el agente SSH antes de abrir KiCad.
- En Windows (Git Bash / PowerShell):
  ```bash
  ssh-add C:\Users\<tu usuario>\.ssh\id_ed25519
  ```
- En macOS/Linux:
  ```bash
  ssh-add ~/.ssh/id_ed25519
  ```
- Si prefieres no escribir la passphrase, puedes dejar la llave sin passphrase al generarla, pero es menos seguro.

### Error "Unable to negotiate ... no matching host key type"

- Este error suele deberse a una llave o algoritmo no soportado por la versión de `libgit2` de KiCad. La solución más sencilla es usar **Ed25519** o **ECDSA** en lugar de RSA.
- Si estás usando una llave RSA muy antigua (formato PEM o firma SHA-1), regenera la llave con el comando moderno de RSA o, preferiblemente, con Ed25519.
- **No se recomienda** agregar configuraciones globales en `~/.ssh/config` para reactivar algoritmos obsoletos (`ssh-rsa` SHA-1), ya que reduce la seguridad de todas las conexiones SSH.

### La conexión SSH funciona en terminal pero no en KiCad

- KiCad puede no detectar automáticamente `id_ed25519`. Selecciónala manualmente con el botón **Browse**.
- Verifica que la llave privada sea el archivo sin extensión `.pub`.
- Asegúrate de que el archivo de la llave esté en formato OpenSSH. Si fue generado por PuTTY, conviértelo o genera una nueva con `ssh-keygen`.

---

## 9. Enlaces útiles

- Generar llaves SSH en GitHub: https://docs.github.com/en/authentication/connecting-to-github-with-ssh/generating-a-new-ssh-key-and-adding-it-to-the-ssh-agent
- Foro de KiCad sobre Git: https://forum.kicad.info/t/tutorial-how-to-enable-git-in-kicad-8/49235
- Documentación de KiCad sobre control de versiones: https://docs.kicad.org/

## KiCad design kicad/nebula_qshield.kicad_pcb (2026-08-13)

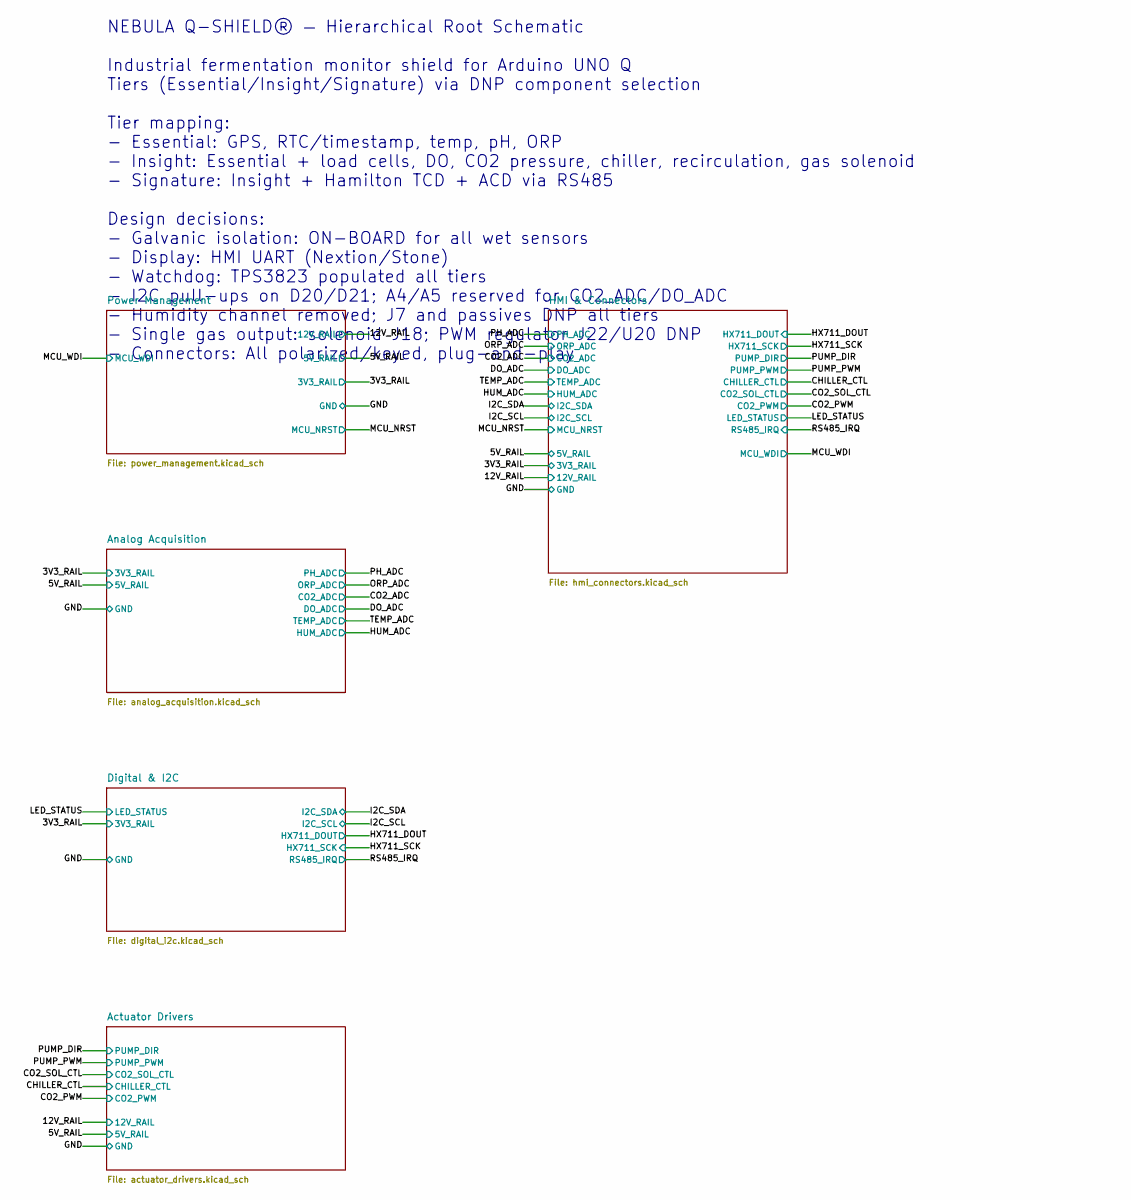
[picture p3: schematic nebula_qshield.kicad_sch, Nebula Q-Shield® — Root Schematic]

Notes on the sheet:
NEBULA Q-SHIELD® — Hierarchical Root Schematic Industrial fermentation monitor shield for Arduino UNO Q Tiers (Essential/Insight/Signature) via DNP component selection Tier mapping: - Essential: GPS, RTC/timestamp, temp, pH, ORP - Insight: Essential + load cells, DO, CO2 pressure, chiller, recircul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

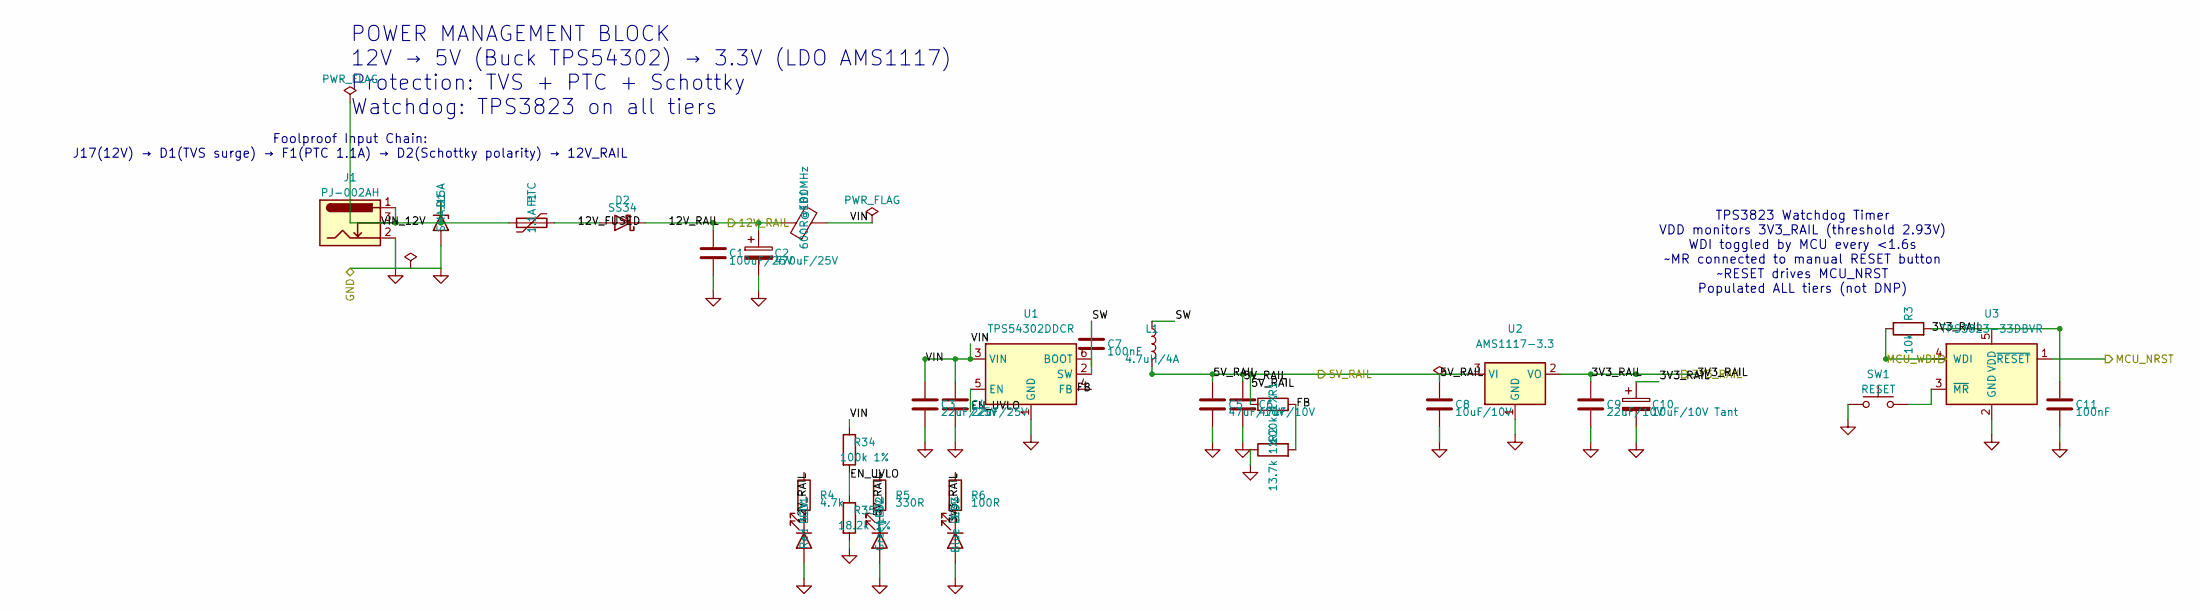
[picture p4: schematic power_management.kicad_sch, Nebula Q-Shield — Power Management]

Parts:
C1: 100uF/25V; C_1210_3225Metric; MPN GRM32ER61E107ME20L
C2: 470uF/25V; CP_Radial_D10.0mm_P5.00mm; MPN UCD1E471MNL1GS
C3, C4: 22uF/25V; C_0805_2012Metric; MPN GRM21BR61E226ME44L
C5, C6: 47uF/10V; C_0805_2012Metric; MPN GRM21BR61A476ME15L
C7, C11: 100nF; C_0402_1005Metric
C8: 10uF/10V; C_0805_2012Metric; MPN GRM21BR61A106KE19L
C9: 22uF/10V; C_0805_2012Metric; MPN GRM21BR61A226ME44L
C10: 10uF/10V Tant; C_1206_3216Metric; MPN T491A106M010AT
D1: SMAJ15A; D_SMA; MPN SMAJ15A; Digi-Key_PN SMAJ15ALFCT-ND
D2: SS34; D_SMA; MPN SS34; Digi-Key_PN SS34-E3/57TCT-ND
F1: 1.1A PTC; Fuse_1812_4532Metric; MPN MF-MSMF110/24X-2; Digi-Key_PN MF-MSMF110/24X-2CT-ND
FB1: 600R@100MHz; L_1206_3216Metric; MPN BLM31PG601SN1L; Digi-Key_PN 490-5222-1-ND
J1: PJ-002AH; BarrelJack_Horizontal; MPN PJ-002AH; Digi-Key_PN CP-002AH-ND
L1: 4.7uH/4A; L_Taiyo-Yuden_NR-40xx; MPN 744043004700; Digi-Key_PN 732-1260-1-ND
LED1: Red 12V; LED_0603_1608Metric; MPN 150060RS75000
LED2: Green 5V; LED_0603_1608Metric; MPN 150060GS75000
LED3: Blue 3.3V; LED_0603_1608Metric; MPN 150060BS75000
R1, R34: 100k 1%; R_0402_1005Metric; MPN CRCW0402100KFKED
R2: 13.7k 1%; R_0402_1005Metric; MPN CRCW040213K7FKED
R3: 10k; R_0402_1005Metric
R4: 4.7k; R_0402_1005Metric
R5: 330R; R_0402_1005Metric
R6: 100R; R_0402_1005Metric
R35: 18.2k 1%; R_0402_1005Metric; MPN CRCW040218K2FKED
SW1: RESET; SW_SPST_TL3342
U1: TPS54302DDCR; SOT-23-6; MPN TPS54302DDCR; Digi-Key_PN 296-50420-1-ND
U2: AMS1117-3.3; SOT-223-3_TabPin2; MPN AMS1117-3.3
U3: TPS3823-33DBVR; SOT-23-5; Digi-Key_PN 296-34371-1-ND

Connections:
/3V3_RAIL: C9.1, C10.1, C11.1, R3.2, R6.1, U2.2 (VO), U3.5 (VDD); also elsewhere on the board
/5V_RAIL: C5.1, C6.1, C8.1, L1.2, R1.1, R5.1, U2.3 (VI); also elsewhere on the board
/12V_RAIL: C1.1, C2.1, D2.1 (K), FB1.1, R4.1; also elsewhere on the board
/MCU_NRST: U3.1 (~RESET); also elsewhere on the board
/MCU_WDI: R3.1, U3.4 (WDI); also elsewhere on the board
/Power Management/12V_FUSED: D2.2 (A), F1.2
/Power Management/EN_UVLO: R34.2, R35.1, U1.5 (EN)
/Power Management/FB: R1.2, R2.2, U1.4 (FB)
/Power Management/SW: C7.1, L1.1, U1.2 (SW)
/Power Management/VIN: C3.1, C4.1, FB1.2, R34.1, U1.3 (VIN)
/Power Management/VIN_12V: D1.1 (A1), F1.1, J1.1, J1.3
GND: C1.2, C2.2, C3.2, C4.2, C5.2, C6.2, C8.2, C9.2, C10.2, C11.2, D1.2 (A2), J1.2, LED1.2 (A), LED2.2 (A), LED3.2 (A), R2.1, R35.2, SW1.1, U1.1 (GND), U2.1 (GND), U3.2 (GND); also elsewhere on the board
unnamed: LED1.1 (K), R4.2
unnamed: LED2.1 (K), R5.2
unnamed: LED3.1 (K), R6.2
unnamed: C7.2, U1.6 (BOOT)
unnamed: SW1.2, U3.3 (~MR)

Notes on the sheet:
POWER MANAGEMENT BLOCK 12V → 5V (Buck TPS54302) → 3.3V (LDO AMS1117) Protection: TVS + PTC + Schottky Watchdog: TPS3823 on all tiers
Foolproof Input Chain: J17(12V) → D1(TVS surge) → F1(PTC 1.1A) → D2(Schottky polarity) → 12V_RAIL
TPS3823 Watchdog Timer VDD monitors 3V3_RAIL (threshold 2.93V) WDI toggled by MCU every <1.6s ~MR connected to manual RESET button ~RESET drives MCU_NRST Populated ALL tiers (not DNP)

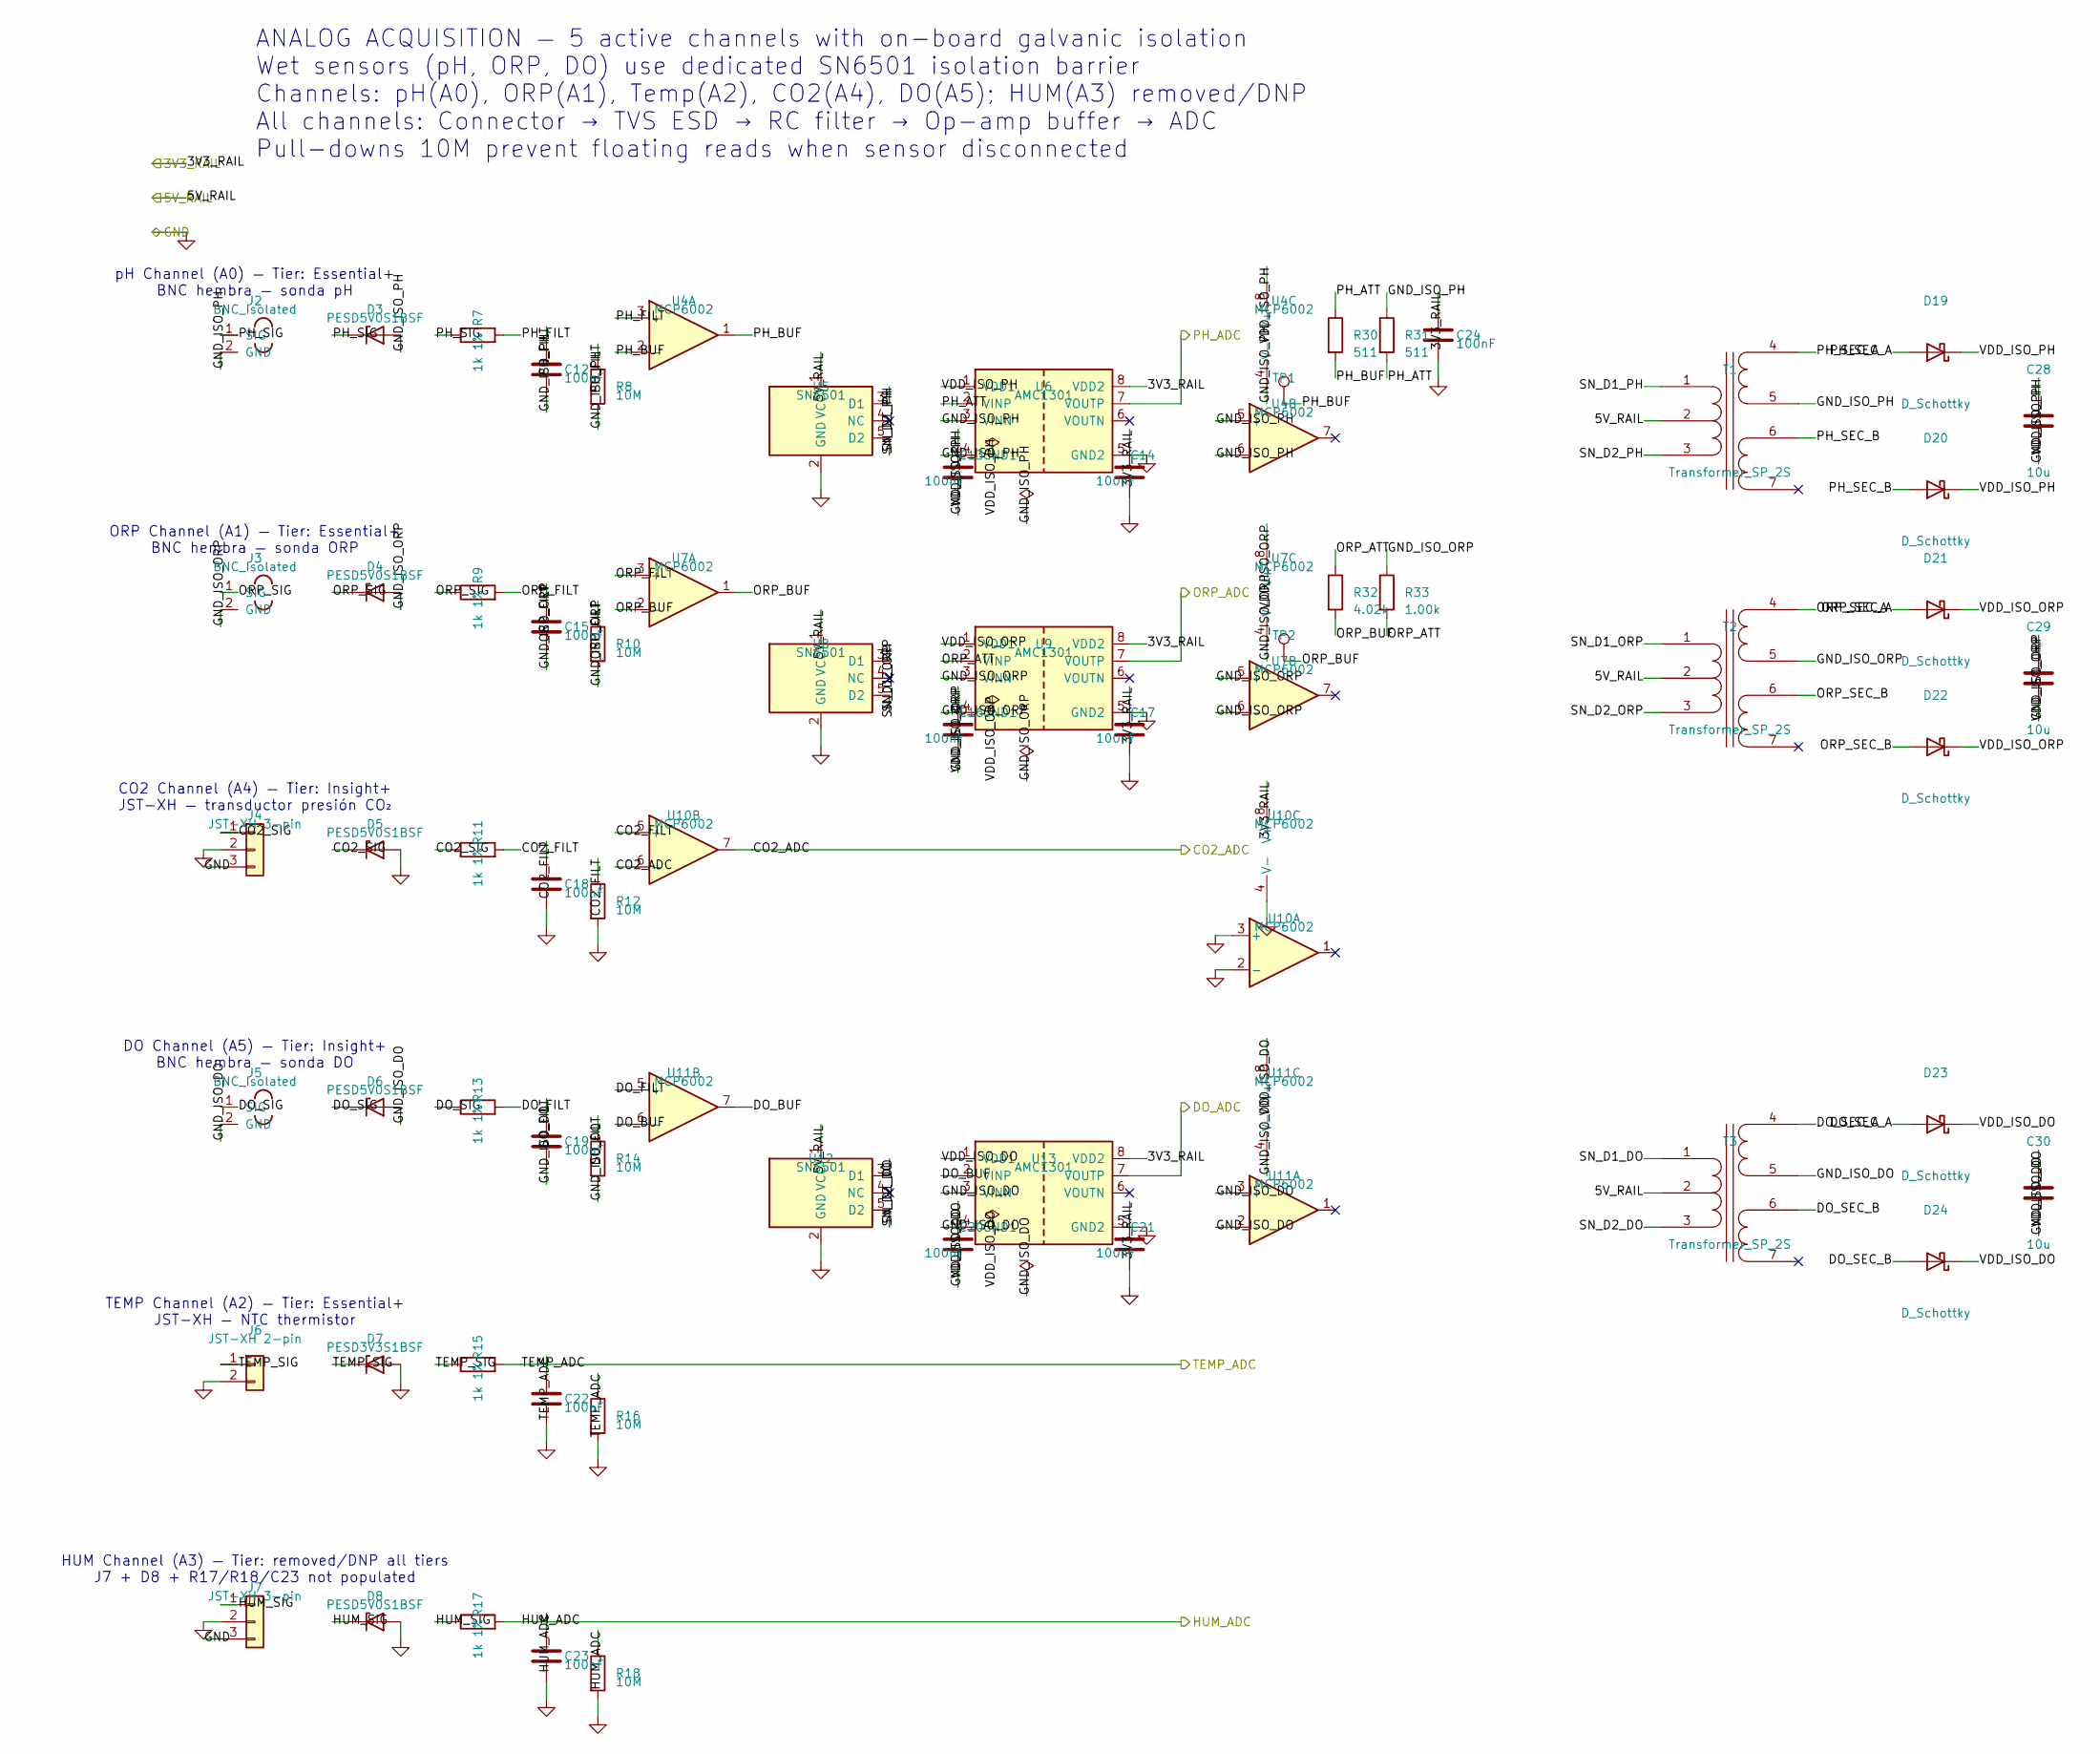
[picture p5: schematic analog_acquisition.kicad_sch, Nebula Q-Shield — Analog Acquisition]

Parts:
C12, C13, C14, C15, C16, C17, C18, C19, C20, C21, C22, C23, C24: 100nF; C_0402_1005Metric
C28, C29, C30: 10u; C_0805_2012Metric; MPN GRM21BR61C106KE15L
D3, D4, D5, D6, D8: PESD5V0S1BSF; D_SOD-323F; MPN PESD5V0S1BSF; Digi-Key_PN 568-13204-1-ND
D7: PESD3V3S1BSF; D_SOD-323F; MPN PESD3V3S1BSF; Digi-Key_PN 568-13206-1-ND
D19, D20, D21, D22, D23, D24: D_Schottky; D_SOD-123; MPN BAT54,115
J2, J3, J5: BNC_Isolated; BNC_Panel_Mount_Isolated
J4, J7: JST-XH 3-pin; JST_XH_B3B-XH-A_1x03_P2.50mm_Vertical
J6: JST-XH 2-pin; JST_XH_B2B-XH-A_1x02_P2.50mm_Vertical
R7, R9, R11, R13, R15, R17: 1k 1%; R_0402_1005Metric; MPN CRCW04021K00FKED
R8, R10, R12, R14, R16, R18: 10M; R_0402_1005Metric
R30, R31: 511; R_0402_1005Metric
R32: 4.02k; R_0402_1005Metric
R33: 1.00k; R_0402_1005Metric
T1, T2, T3: Transformer_SP_2S; Transformer_Wuerth_750315371; MPN 750315371
TP1, TP2: TestPoint; TestPoint_Pad_D1.5mm
U4, U7, U10, U11: MCP6002; SOIC-8_3.9x4.9mm_P1.27mm; MPN MCP6002-I/SN; Digi-Key_PN MCP6002-I/SN-ND
U5, U8, U12: SN6501; SOT-23-5
U6, U9, U13: AMC1301; SOIC-8_3.9x4.9mm_P1.27mm; MPN AMC1301DWVR

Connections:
/3V3_RAIL: C14.1, C17.1, C21.1, C24.1, U6.8 (VDD2), U9.8 (VDD2), U10.8 (V+), U13.8 (VDD2); also elsewhere on the board
/5V_RAIL: T1.2 (PM), T2.2 (PM), T3.2 (PM), U5.1 (VCC), U8.1 (VCC), U12.1 (VCC); also elsewhere on the board
/Analog Acquisition/CO2_FILT: C18.1, R11.2, R12.1, U10.5 (+)
/Analog Acquisition/CO2_SIG: D5.1 (K), J4.1, R11.1
/Analog Acquisition/DO_BUF: U11.6 (-), U11.7, U13.2 (VINP)
/Analog Acquisition/DO_FILT: C19.1, R13.2, R14.1, U11.5 (+)
/Analog Acquisition/DO_SEC_A: D23.2 (A), T3.4 (OUT1A)
/Analog Acquisition/DO_SEC_B: D24.2 (A), T3.6 (OUT2A)
/Analog Acquisition/DO_SIG: D6.1 (K), J5.1 (SIG), R13.1
/Analog Acquisition/GND_ISO_DO: C19.2, C20.2, C30.2, D6.2 (A), J5.2 (GND), R14.2, T3.5 (OUT1B), U11.2 (-), U11.3 (+), U11.4 (V-), U13.3 (VINN), U13.4 (GND1)
/Analog Acquisition/GND_ISO_ORP: C15.2, C16.2, C29.2, D4.2 (A), J3.2 (GND), R10.2, R33.1, T2.5 (OUT1B), U7.4 (V-), U7.5 (+), U7.6 (-), U9.3 (VINN), U9.4 (GND1)
/Analog Acquisition/GND_ISO_PH: C12.2, C13.2, C28.2, D3.2 (A), J2.2 (GND), R8.2, R31.1, T1.5 (OUT1B), U4.4 (V-), U4.5 (+), U4.6 (-), U6.3 (VINN), U6.4 (GND1)
/Analog Acquisition/HUM_SIG: D8.1 (K), J7.1, R17.1
/Analog Acquisition/ORP_ATT: R32.1, R33.2, U9.2 (VINP)
/Analog Acquisition/ORP_BUF: R32.2, TP2.1, U7.1, U7.2 (-)
/Analog Acquisition/ORP_FILT: C15.1, R9.2, R10.1, U7.3 (+)
/Analog Acquisition/ORP_SEC_A: D21.2 (A), T2.4 (OUT1A)
/Analog Acquisition/ORP_SEC_B: D22.2 (A), T2.6 (OUT2A)
/Analog Acquisition/ORP_SIG: D4.1 (K), J3.1 (SIG), R9.1
/Analog Acquisition/PH_ATT: R30.1, R31.2, U6.2 (VINP)
/Analog Acquisition/PH_BUF: R30.2, TP1.1, U4.1, U4.2 (-)
/Analog Acquisition/PH_FILT: C12.1, R7.2, R8.1, U4.3 (+)
/Analog Acquisition/PH_SEC_A: D19.2 (A), T1.4 (OUT1A)
/Analog Acquisition/PH_SEC_B: D20.2 (A), T1.6 (OUT2A)
/Analog Acquisition/PH_SIG: D3.1 (K), J2.1 (SIG), R7.1
/Analog Acquisition/SN_D1_DO: T3.1 (IN+), U12.3 (D1)
/Analog Acquisition/SN_D1_ORP: T2.1 (IN+), U8.3 (D1)
/Analog Acquisition/SN_D1_PH: T1.1 (IN+), U5.3 (D1)
/Analog Acquisition/SN_D2_DO: T3.3 (IN-), U12.5 (D2)
/Analog Acquisition/SN_D2_ORP: T2.3 (IN-), U8.5 (D2)
/Analog Acquisition/SN_D2_PH: T1.3 (IN-), U5.5 (D2)
/Analog Acquisition/TEMP_SIG: D7.1 (K), J6.1, R15.1
/Analog Acquisition/VDD_ISO_DO: C20.1, C30.1, D23.1 (K), D24.1 (K), U11.8 (V+), U13.1 (VDD1)
/Analog Acquisition/VDD_ISO_ORP: C16.1, C29.1, D21.1 (K), D22.1 (K), U7.8 (V+), U9.1 (VDD1)
/Analog Acquisition/VDD_ISO_PH: C13.1, C28.1, D19.1 (K), D20.1 (K), U4.8 (V+), U6.1 (VDD1)
/CO2_ADC: U10.6 (-), U10.7; also elsewhere on the board
/DO_ADC: U13.7 (VOUTP); also elsewhere on the board
/HUM_ADC: C23.1, R17.2, R18.1; also elsewhere on the board
/ORP_ADC: U9.7 (VOUTP); also elsewhere on the board
/PH_ADC: U6.7 (VOUTP); also elsewhere on the board
/TEMP_ADC: C22.1, R15.2, R16.1; also elsewhere on the board
GND: C14.2, C17.2, C18.2, C21.2, C22.2, C23.2, C24.2, D5.2 (A), D7.2 (A), D8.2 (A), J4.2, J4.3, J6.2, J7.2, J7.3, R12.2, R16.2, R18.2, U5.2 (GND), U6.5 (GND2), U8.2 (GND), U9.5 (GND2), U10.2 (-), U10.3 (+), U10.4 (V-), U12.2 (GND), U13.5 (GND2); also elsewhere on the board

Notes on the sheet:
pH Channel (A0) — Tier: Essential+ BNC hembra — sonda pH
ORP Channel (A1) — Tier: Essential+ BNC hembra — sonda ORP
CO2 Channel (A4) — Tier: Insight+ JST-XH — transductor presión CO₂
DO Channel (A5) — Tier: Insight+ BNC hembra — sonda DO
TEMP Channel (A2) — Tier: Essential+ JST-XH — NTC thermistor
HUM Channel (A3) — Tier: removed/DNP all tiers J7 + D8 + R17/R18/C23 not populated
ANALOG ACQUISITION — 5 active channels with on-board galvanic isolation Wet sensors (pH, ORP, DO) use dedicated SN6501 isolation barrier Channels: pH(A0), ORP(A1), Temp(A2), CO2(A4), DO(A5); HUM(A3) removed/DNP All channels: Connector → TVS ESD → RC filter → Op-amp buffer → ADC Pull-downs 10M preve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

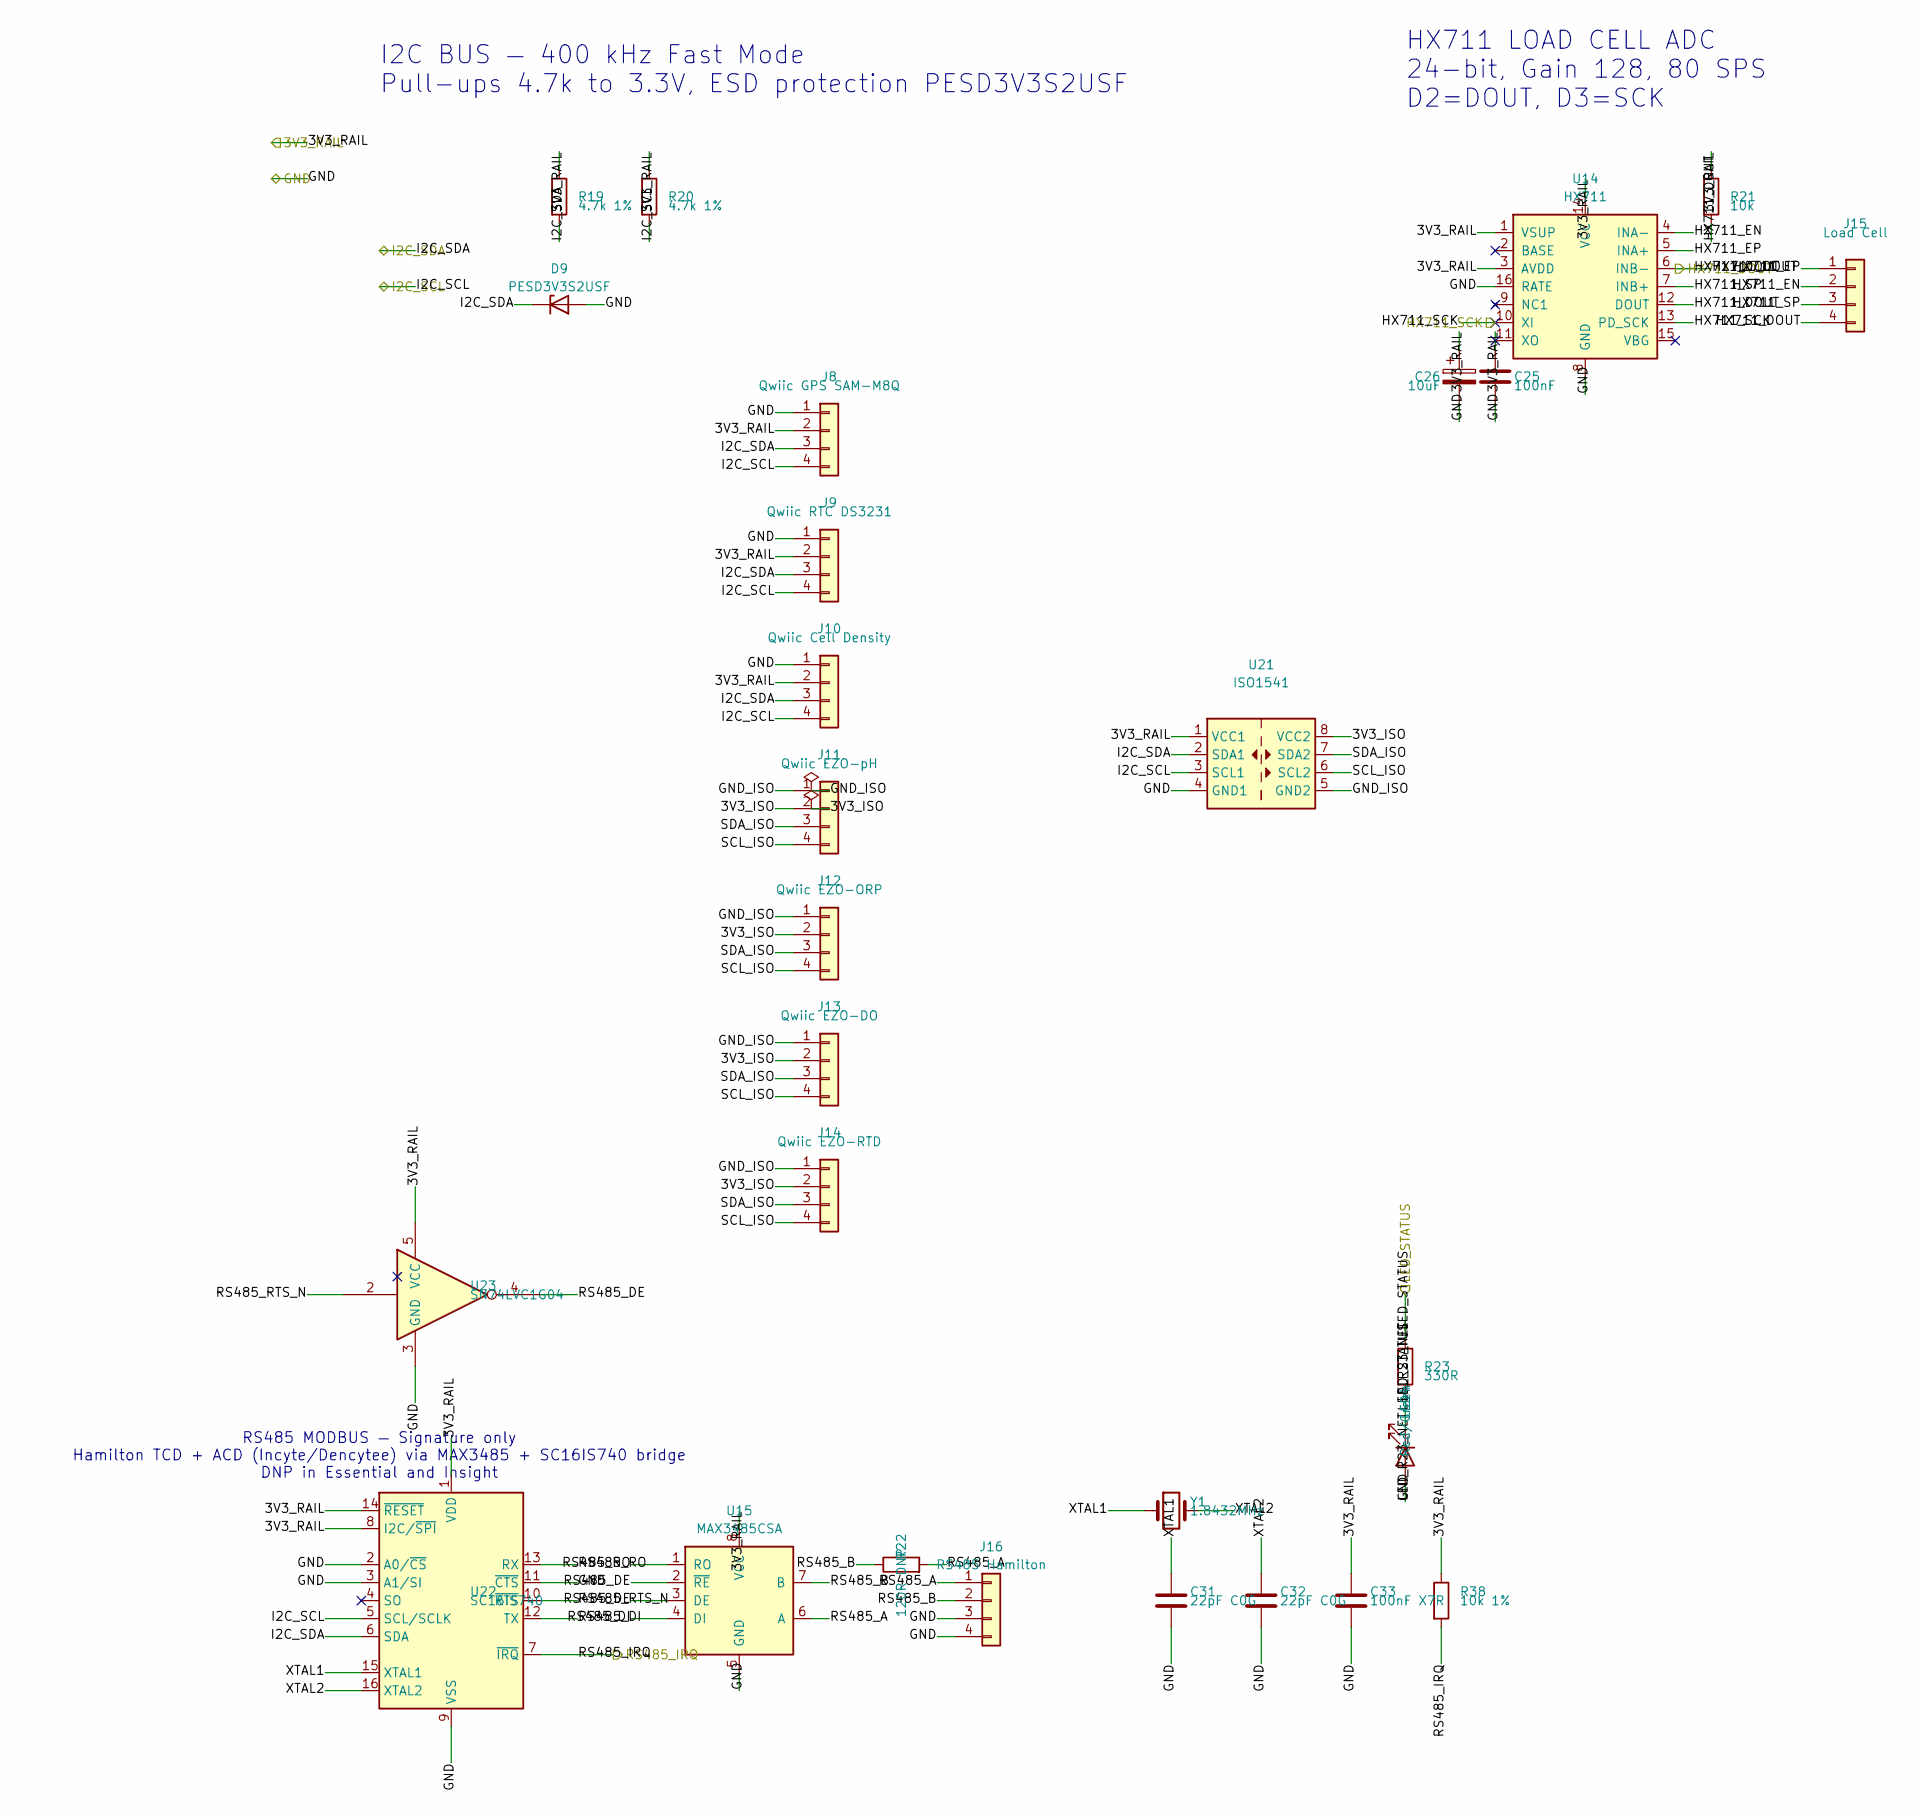
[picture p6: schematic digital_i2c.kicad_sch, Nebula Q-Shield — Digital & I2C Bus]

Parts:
C25: 100nF; C_0402_1005Metric
C26: 10uF; C_0805_2012Metric
C31, C32: 22pF C0G; C_0402_1005Metric; MPN CL05C220JB5NNNC; Digi-Key_PN 1276-1013-1-ND
C33: 100nF X7R; C_0402_1005Metric; MPN CL05B104KO5NNNC; Digi-Key_PN 1276-1000-1-ND
D9: PESD3V3S2USF; SOT-23-3; MPN PESD3V3S2USF; Digi-Key_PN 568-13207-1-ND
J8: Qwiic GPS SAM-M8Q; JST_SH_SM04B-SRSS-TB_1x04-1MP_P1.00mm_Horizontal; MPN SM04B-SRSS-TB(LF)(SN); Digi-Key_PN 455-1804-1-ND
J9: Qwiic RTC DS3231; JST_SH_SM04B-SRSS-TB_1x04-1MP_P1.00mm_Horizontal; MPN SM04B-SRSS-TB(LF)(SN); Digi-Key_PN 455-1804-1-ND
J10: Qwiic Cell Density; JST_SH_SM04B-SRSS-TB_1x04-1MP_P1.00mm_Horizontal; MPN SM04B-SRSS-TB(LF)(SN); Digi-Key_PN 455-1804-1-ND
J11: Qwiic EZO-pH; JST_SH_SM04B-SRSS-TB_1x04-1MP_P1.00mm_Horizontal; MPN SM04B-SRSS-TB(LF)(SN); Digi-Key_PN 455-1804-1-ND
J12: Qwiic EZO-ORP; JST_SH_SM04B-SRSS-TB_1x04-1MP_P1.00mm_Horizontal; MPN SM04B-SRSS-TB(LF)(SN); Digi-Key_PN 455-1804-1-ND
J13: Qwiic EZO-DO; JST_SH_SM04B-SRSS-TB_1x04-1MP_P1.00mm_Horizontal; MPN SM04B-SRSS-TB(LF)(SN); Digi-Key_PN 455-1804-1-ND
J14: Qwiic EZO-RTD; JST_SH_SM04B-SRSS-TB_1x04-1MP_P1.00mm_Horizontal; MPN SM04B-SRSS-TB(LF)(SN); Digi-Key_PN 455-1804-1-ND
J15: Load Cell; TerminalBlock_Phoenix_PT-1,5-4-5.0-H_1x04_P5.00mm_Horizontal; MPN 1757242; Digi-Key_PN 277-1274-ND
J16: RS485 Hamilton; TerminalBlock_Phoenix_PT-1,5-4-5.0-H_1x04_P5.00mm_Horizontal
LED4: Red/Green; LED_0603_1608Metric
R19: 4.7k 1%; R_0402_1005Metric; MPN CRCW04024K70FKED; Digi-Key_PN 541-4.70KLCT-ND
R20: 4.7k 1%; R_0402_1005Metric; MPN CRCW04024K70FKED
R21: 10k; R_0402_1005Metric
R22: 120R DNP; R_0402_1005Metric
R23: 330R; R_0402_1005Metric
R38: 10k 1%; R_0402_1005Metric; MPN CRCW040210K0FKED; Digi-Key_PN 541-10.0KLCT-ND
U14: HX711; SOP-16_4.4x10.4mm_P1.27mm
U15: MAX3485CSA; SOIC-8_3.9x4.9mm_P1.27mm
U21: ISO1541; SOIC-8_3.9x4.9mm_P1.27mm; MPN ISO1541DR
U22: SC16IS740; TSSOP-16_4.4x5mm_P0.65mm; MPN SC16IS740IPW/Q900; Digi-Key_PN 568-13068-1-ND
U23: SN74LVC1G04; SOT-353_SC-70-5; MPN SN74LVC1G04DCKR; Digi-Key_PN 296-11602-1-ND
Y1: 1.8432MHz; Crystal_SMD_HC49-SD; MPN ABLS-1.8432MHZ-B4-T; Digi-Key_PN 535-9930-1-ND

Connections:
/3V3_RAIL: C25.1, C26.1, C33.1, J8.2, J9.2, J10.2, R19.1, R20.1, R21.1, R38.1, U14.1 (VSUP), U14.3 (AVDD), U14.14 (VCC), U15.8 (VCC), U21.1 (VCC1), U22.1 (VDD), U22.8 (I2C/~SPI), U22.14 (~RESET), U23.5 (VCC); also elsewhere on the board
/Digital & I2C/3V3_ISO: J11.2, J12.2, J13.2, J14.2, U21.8 (VCC2)
/Digital & I2C/GND_ISO: J11.1, J12.1, J13.1, J14.1, U21.5 (GND2)
/Digital & I2C/HX711_EN: J15.2, U14.4 (INA-)
/Digital & I2C/HX711_EP: J15.1, U14.5 (INA+)
/Digital & I2C/HX711_SP: J15.3, U14.7 (INB+)
/Digital & I2C/LED_R23_NET: LED4.1 (K), R23.2
/Digital & I2C/RS485_A: J16.1, R22.2, U15.6 (A)
/Digital & I2C/RS485_B: J16.2, R22.1, U15.7 (B)
/Digital & I2C/RS485_DE: U15.2 (~RE), U15.3 (DE), U23.4
/Digital & I2C/RS485_DI: U15.4 (DI), U22.12 (TX)
/Digital & I2C/RS485_RO: U15.1 (RO), U22.13 (RX)
/Digital & I2C/RS485_RTS_N: U22.10 (~RTS), U23.2
/Digital & I2C/SCL_ISO: J11.4, J12.4, J13.4, J14.4, U21.6 (SCL2)
/Digital & I2C/SDA_ISO: J11.3, J12.3, J13.3, J14.3, U21.7 (SDA2)
/Digital & I2C/XTAL1: C31.1, U22.15 (XTAL1), Y1.1
/Digital & I2C/XTAL2: C32.1, U22.16 (XTAL2), Y1.2
/HX711_DOUT: J15.4, R21.2, U14.6 (INB-), U14.12 (DOUT); also elsewhere on the board
/HX711_SCK: U14.10 (XI), U14.13 (PD_SCK); also elsewhere on the board
/I2C_SCL: J8.4, J9.4, J10.4, R20.2, U21.3 (SCL1), U22.5 (SCL/SCLK); also elsewhere on the board
/I2C_SDA: D9.1 (K), J8.3, J9.3, J10.3, R19.2, U21.2 (SDA1), U22.6 (SDA); also elsewhere on the board
/LED_STATUS: R23.1; also elsewhere on the board
/RS485_IRQ: R38.2, U22.7 (~IRQ); also elsewhere on the board
GND: C25.2, C26.2, C31.2, C32.2, C33.2, D9.2 (A), J8.1, J9.1, J10.1, J16.3, J16.4, LED4.2 (A), U14.8 (GND), U14.16 (RATE), U15.5 (GND), U21.4 (GND1), U22.2 (A0/~CS), U22.3 (A1/SI), U22.9 (VSS), U22.11 (~CTS), U23.3 (GND); also elsewhere on the board

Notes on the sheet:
I2C BUS — 400 kHz Fast Mode Pull-ups 4.7k to 3.3V, ESD protection PESD3V3S2USF
HX711 LOAD CELL ADC 24-bit, Gain 128, 80 SPS D2=DOUT, D3=SCK
RS485 MODBUS — Signature only Hamilton TCD + ACD (Incyte/Dencytee) via MAX3485 + SC16IS740 bridge DNP in Essential and Insight

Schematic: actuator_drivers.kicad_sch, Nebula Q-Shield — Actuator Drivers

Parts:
C27: 100nF; C_0402_1005Metric
D10, D11, D14: SS34; D_SMA
D12, D13: 1N4148W; D_SOD-323
F2: 1A PTC; Fuse_0805_2012Metric; MPN MF-PSMF110X-2
F3: 0.5A PTC; Fuse_0805_2012Metric; MPN MF-PSMF050X-2
F4: 0.5A PTC; Fuse_0805_2012Metric
J17: Motor 12V; TerminalBlock_Phoenix_PT-1,5-2-5.0-H_1x02_P5.00mm_Horizontal; MPN 1757229
J18: CO2 Solenoid; TerminalBlock_Phoenix_PT-1,5-2-5.0-H_1x02_P5.00mm_Horizontal
J19: Chiller; TerminalBlock_Phoenix_PT-1,5-2-5.0-H_1x02_P5.00mm_Horizontal
J22: CO2 Valve; PhoenixContact_MC_1,5_2-G-3.81_1x02_P3.81mm_Horizontal; MPN 1757229
K1: HF46F-12-HS1; Relay_SPDT_Omron_G5V-1; MPN HF46F-12-HS1; Digi-Key_PN 255-5799-ND
K2: HF46F-12-HS1; Relay_SPDT_Omron_G5V-1
Q1: IRLZ44NPBF; TO-220-3_Vertical; MPN IRLZ44NPBF; Digi-Key_PN IRLZ44NPBF-ND
Q2, Q5: IRLZ44NPBF; TO-220-3_Vertical
Q3, Q4: 2N7002; SOT-23
R24, R25, R26, R27: 1k; R_0402_1005Metric
R28: 10k; R_0402_1005Metric
U16: PC817X2NIP; DIP-8_W7.62mm; MPN PC817X2NIP
U17: IR2104SPBF; SOIC-8_3.9x4.9mm_P1.27mm; MPN IR2104SPBF; Digi-Key_PN IR2104SPBF-ND
U18, U19: PC817X1NIP; DIP-4_W7.62mm
U20: MCP6002; SOIC-8_3.9x4.9mm_P1.27mm

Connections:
/5V_RAIL: U20.8 (V+); also elsewhere on the board
/12V_RAIL: D10.1 (K), D12.1 (K), D13.1 (K), D14.1 (K), K1.2, K2.2, Q1.2 (D), U17.1 (VCC), U17.3 (~SD); also elsewhere on the board
/Actuator Drivers/CHILLER_ISO: Q4.1 (G), U19.4
/Actuator Drivers/CHILLER_NO: F4.1, K2.10
/Actuator Drivers/CHILLER_OUT: F4.2, J19.1, K2.1
/Actuator Drivers/CO2_PWM_FILT: C27.1, R28.1, U20.5 (+)
/Actuator Drivers/CO2_PWM_OUT: Q5.1 (G), U20.6 (-), U20.7
/Actuator Drivers/CO2_SOL_ISO: Q3.1 (G), U18.4
/Actuator Drivers/CO2_SOL_NO: F3.1, K1.10
/Actuator Drivers/CO2_SOL_OUT: F3.2, J18.1, K1.1
/Actuator Drivers/CO2_VALVE: D14.2 (A), Q5.2 (D)
/Actuator Drivers/K1_COIL_N: D12.2 (A), K1.9, Q3.3 (D)
/Actuator Drivers/K2_COIL_N: D13.2 (A), K2.9, Q4.3 (D)
/Actuator Drivers/MOTOR_HO: Q1.1 (G), U17.7 (HO)
/Actuator Drivers/MOTOR_LO: Q2.1 (G), U17.5 (LO)
/Actuator Drivers/MOTOR_VB: F2.2, J17.1, U17.8 (VB)
/Actuator Drivers/MOTOR_VS: D10.2 (A), D11.1 (K), F2.1, Q1.3 (S), Q2.2 (D), U17.6 (VS)
/Actuator Drivers/PUMP_DIR_ISO: U16.4, U17.2 (IN)
/Actuator Drivers/U16_INA: R24.2, U16.1
/Actuator Drivers/U18_IN: R26.2, U18.1
/Actuator Drivers/U19_IN: R27.2, U19.1
/CHILLER_CTL: R27.1; also elsewhere on the board
/CO2_PWM: R28.2; also elsewhere on the board
/CO2_SOL_CTL: R26.1; also elsewhere on the board
/PUMP_DIR: R24.1; also elsewhere on the board
/PUMP_PWM: R25.1; also elsewhere on the board
GND: C27.2, D11.2 (A), J17.2, J18.2, J19.2, Q2.3 (S), Q3.2 (S), Q4.2 (S), Q5.3 (S), R25.2, U16.2, U16.3, U17.4 (COM), U18.2, U18.3, U19.2, U19.3, U20.3 (+), U20.4 (V-); also elsewhere on the board
unnamed: U20.1, U20.2 (-)

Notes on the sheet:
ACTUATOR DRIVERS — All opto-isolated from MCU Motor/recirculation: IR2104 + IRLZ44N (Insight+) Gas solenoid (CO2/H2): PC817 + 2N7002 + HF46F (Insight+) Chiller relay: PC817 + 2N7002 + HF46F (Insight+) CO2 PWM proportional valve: DNP all tiers (single gas via solenoid)
GAS SOLENOID RELAY (CO2/H2) — Insight+ MCU CO2_SOL_CTL → R26 → U18 → Q3 → Relay K1 → J18
CHILLER RELAY — Insight+ MCU CHILLER_CTL → R27 → U19 → Q4 → Relay K2 → J19
GAS PWM FLOW REGULATOR — DNP all tiers Single gas output uses solenoid K1/J18; U20/Q5/D14/R28/C27/J22 not populated
U20 unused sections

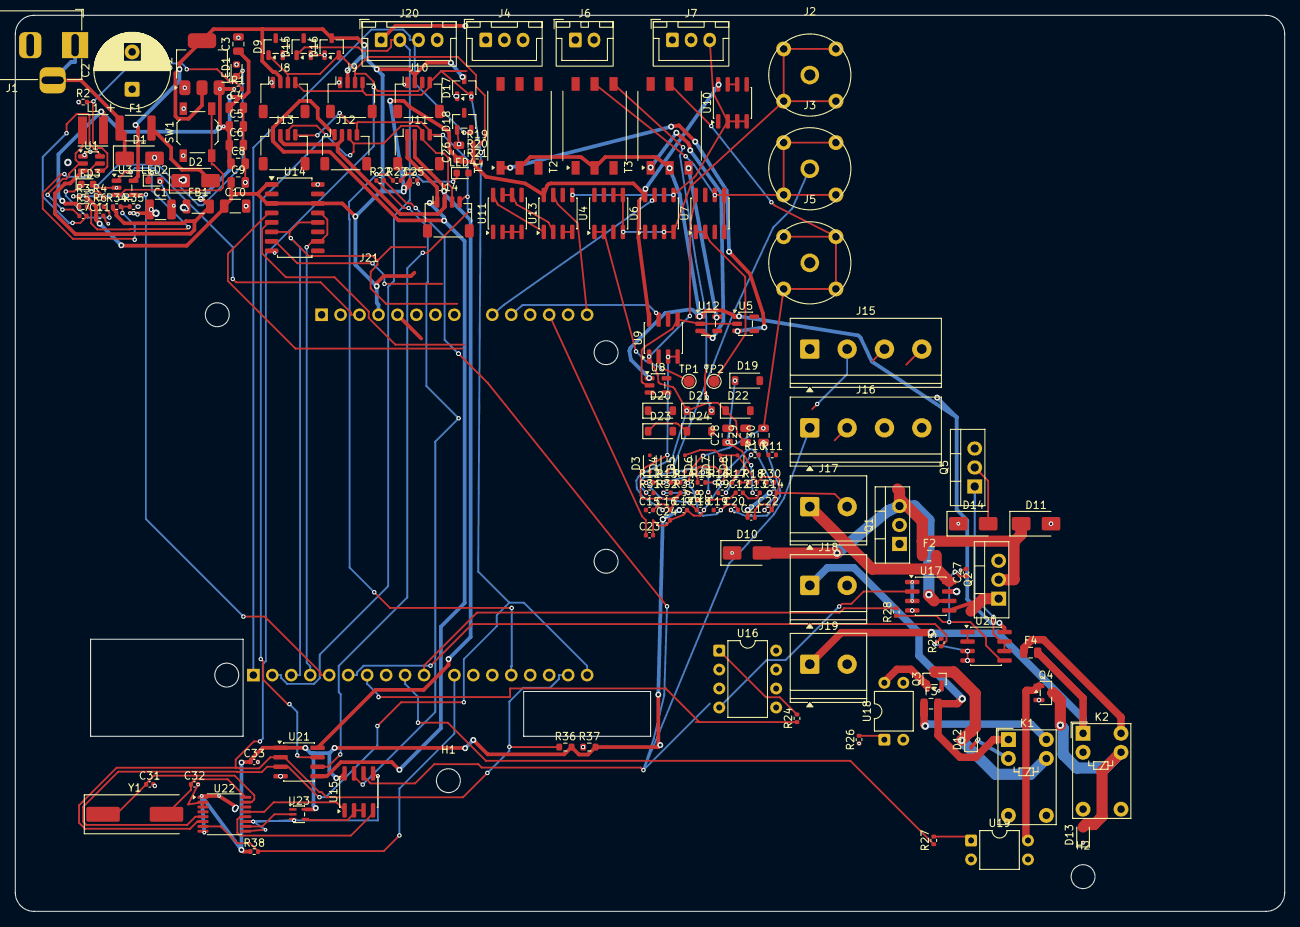
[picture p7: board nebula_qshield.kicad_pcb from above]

Board: 4 copper layers, 170.0 x 120.0 mm, 164 parts (0 on the bottom side), 105 nets.

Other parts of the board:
D15: PESD3V3S2USF; SOT-23-3
D16, D17, D18: BAT54S; SOT-23-3
H1, H2: MountingHole_3.2mm_M3
J20: J20; JST_XH_B4B-XH-A_1x04_P2.50mm_Vertical
J21: Arduino UNO Q Shield; Arduino_UNO_Q_Shield
R36, R37: 4.7k; R_0603_1608Metric

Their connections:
/3V3_RAIL: D16.3, D17.3, J21.4, R36.2, R37.2; also elsewhere on the board
/5V_RAIL: D18.3, J20.1, J21.5; also elsewhere on the board
/12V_RAIL: J21.8; also elsewhere on the board
/CHILLER_CTL: J21.23; also elsewhere on the board
/CO2_ADC: J21.13; also elsewhere on the board
/CO2_PWM: J21.24; also elsewhere on the board
/CO2_SOL_CTL: J21.22; also elsewhere on the board
/DO_ADC: J21.14; also elsewhere on the board
/HMI & Connectors/HMI_RX: D18.2, J20.3, J21.15
/HMI & Connectors/HMI_TX: D15.1, J20.2, J21.16
/HUM_ADC: J21.12; also elsewhere on the board
/HX711_DOUT: J21.17; also elsewhere on the board
/HX711_SCK: J21.18; also elsewhere on the board
/I2C_SCL: D17.2, J21.32, R37.1; also elsewhere on the board
/I2C_SDA: D16.2, J21.31, R36.1; also elsewhere on the board
/LED_STATUS: J21.28; also elsewhere on the board
/MCU_NRST: J21.3; also elsewhere on the board
/MCU_WDI: J21.19; also elsewhere on the board
/ORP_ADC: J21.10; also elsewhere on the board
/PH_ADC: J21.9; also elsewhere on the board
/PUMP_DIR: J21.21; also elsewhere on the board
/PUMP_PWM: J21.20; also elsewhere on the board
/RS485_IRQ: J21.25; also elsewhere on the board
/TEMP_ADC: J21.11; also elsewhere on the board
GND: D15.2, D16.1, D17.1, D18.1, J20.4, J21.6, J21.7, J21.29; also elsewhere on the board

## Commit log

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2026-05-27 feat: Add complete KiCad 8.x hierarchical schematics for Nebula Q-Shield
    Hierarchical schematic structure (root + 5 sub-sheets):
    - nebula_qshield.kicad_sch (root with 5 hierarchical sheet blocks)
    - power_management.kicad_sch (12V protection, TPS54302 buck, AMS1117 LDO, TPS3823 watchdog)
    - analog_acquisition.kicad_sch (6 channels: pH/ORP/CO2/DO/Temp/Hum with galvanic isolation)
    - digital_i2c.kicad_sch (I2C bus, HX711 load cell ADC, RS485 DNP, status LED)
    - actuator_drivers.kicad_sch (IR2104 motor driver, 2x relay, CO2 PWM, all opto-isolated)
    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
    [actuator_drivers.kicad_sch, analog_acquisition.kicad_sch, digital_i2c.kicad_sch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]
2026-05-27 docs: Update all documentation to reflect HMI UART (replaces HDMI)
    Changes across 7 files:
    README.md:
    - Replace HDMI references with HMI UART (Nextion/Stone)
    - Update file structure tree to show actual KiCad hierarchical files
    - Add schematic hierarchy overview section
    - Update watchdog description (dual: TPS3823 + IWDG)
    - Add galvanic isolation on-board mention
    docs/01_PCB_ARCHITECTURE.md:
    - Replace Section 2.6 'Bloque de Display' with 'Bloque de HMI'
    - Remove J15 (Micro-HDMI) and J16 (USB-A) from connector table
    - Add J_HMI (JST-XH 4-pin) and J_RS485 (terminal block)
    - Update tier matrix: 'HMI UART (Nextion)' replaces 'Display (HDMI+USB)'
    docs/02_FOOLPROOF_DESIGN.md:
    - Replace HDMI/USB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
2026-05-28 fix: Remove ;; comments from all KiCad files (syntax error in KiCad 9)
    KiCad S-expression files do not support ;; comments — the parser
    expects '(' tokens only. Removed all comment lines from:
    - lib/nebula_symbols.kicad_sym (caused 'Expecting (' error on load)
    - All 6 .kicad_sch schematic files
    - nebula_qshield.kicad_dru design rules file
    Fixes: 'Symbol library nebula_symbols failed to load' error in KiCad 9.0
    [actuator_drivers.kicad_sch, analog_acquisition.kicad_sch, digital_i2c.kicad_sch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]
2026-05-28 fix: Replace invalid 'net_label' with 'label' in power_management schematic
    KiCad S-expression format uses 'label' not 'net_label' for net labels.
    This caused: 'Errors occurred attempting to load hierarchical sheets' at
    power_management.kicad_sch line 635.
    [power_management.kicad_sch]
2026-05-28 fix: Resolve 5 ERC warnings — footprints, grid alignment, net conflict
    1. Inductor footprint: L_4.0x4.0mm_H2.0mm → L_Taiyo-Yuden_NR-40xx
    (power_management.kicad_sch)
    2. Relay footprint (×2): Relay_SPST_HF46F → Relay_SPDT_Omron_G5V-1
    (actuator_drivers.kicad_sch — K1, K2)
    3. Off-grid coordinates: TPS3823 symbol and WDT_RESET label moved
    from 300.48/310.64 to 300.99/311.15 (1.27mm grid aligned)
    PWR_FLAG reference position 28.575 → 27.94
    (power_management.kicad_sch)
    4. HUM_ADC/I2C_SDA overlap: Both hierarchical labels were at same
    coordinates (55.88, 107.95). Shifted I2C_SDA and downstream
    labels down by 2.54mm each to eliminate net conflict.
    (hmi_connectors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
    [actuator_drivers.kicad_sch, hmi_connectors.kicad_sch, power_management.kicad_sch]
2026-06-02 fix: Add fp-lib-table and sym-lib-table for project-level library registration
    KiCad 9.0 ERC reports 4 warnings because the custom footprint library
    'nebula_footprints' is not registered in the project configuration.
    Creates:
    - kicad/fp-lib-table: registers nebula_footprints.pretty
    - kicad/sym-lib-table: registers nebula_symbols.kicad_sym
    Both use ${KIPRJMOD} relative paths so they work on any machine
    after cloning the repo.
2026-06-02 feat: Wire power_management schematic — 63 wires, 20 GND symbols, 8 labels, 15 junctions
    Complete wiring of the power management sub-sheet:
    Input protection chain:
    - J17 barrel jack → D1 TVS shunt (rot 270°) → F1 PTC fuse (rot 90°)
    → D2 Schottky (rot 180°) → 12V_RAIL bus
    - C1/C2 bulk caps on 12V_RAIL, FB1 ferrite bead (rot 90°)
    Buck converter (TPS54302 12V→5V):
    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
    [power_management.kicad_sch]
2026-06-04 fix: Remove duplicate elements and fix float precision in schematics
    power_management.kicad_sch:
    - Remove 63 duplicated wires (same coordinates, different UUIDs)
    - Remove 20 duplicated GND power symbols (same refs #PWR001-020)
    - Remove 8 duplicated net labels
    - Remove 15 duplicated junctions
    - Remove 1 zero-length wire (both endpoints at same coordinate)
    - Fix floating-point precision errors (e.g. 88.89999999999999 -> 88.9)
    analog_acquisition.kicad_sch:
    - Fix 120 floating-point precision issues in coordinates
    digital_i2c.kicad_sch:
    - Fix 19 floating-point precision issues in coordinates
    These issues caused KiCad 9.0 to crash when running ERC. The duplicate
    GND symbols with the same refere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
    [analog_acquisition.kicad_sch, digital_i2c.kicad_sch, power_management.kicad_sch]
2026-06-04 fix: Embed lib_symbols, fix invalid lib_ids, bump to KiCad 9 format
    - Embed complete (lib_symbols) definitions in all 5 sub-sheets so symbols
    render as real parts instead of '??' placeholders (files now self-contained)
    - Substitute invalid lib_ids with valid library symbols:
    Device:CP -> Device:C_Polarized, Diode:PESD3V3S2USF -> Diode:PESD3V3S1UL,
    Diode:PESD5V0S1BSF -> Diode:PESD5V0S1UL, Isolator:PC817X2 -> Isolator:PC817
    - Bump file format version 20231120 -> 20250114 (removes 'older version' warning)
    - Left-justify header text blocks so long lines stay within the A3 frame
    Validated: kicad-cli SVG render (all real symbols, within frame), clean-room
    eeschema GUI render with broken lib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
    [actuator_drivers.kicad_sch, analog_acquisition.kicad_sch, digital_i2c.kicad_sch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]
2026-06-04 fix: Re-annotate components with unique global references + add instances blocks
    Root cause: symbol instances lacked (instances ...) blocks, so KiCad treated
    all references as unannotated/duplicated (108 duplicate_reference ERC errors)
    and produced auto-renamed names (C_DO2, U3_2A, ...) on annotation.
    Fix: assign globally-unique sequential standard references (R1..R28, C1..C27,
    U1..U20, D1..D18, J1..J21, etc.) and embed a proper (instances) block per
    symbol with the correct hierarchical path. Each MCP6002 kept as its own IC
    (unit A) to preserve per-channel galvanic isolation (pH/ORP/DO).
    ERC: duplicate_reference 108 -> 0, unannotated 1 -> 0.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
    [actuator_drivers.kicad_sch, analog_acquisition.kicad_sch, digital_i2c.kicad_sch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]
2026-06-04 fix: remove redundant WDT_RESET label (resolves multiple_net_names ERC warning)
    [power_management.kicad_sch]
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2026-06-30 fix: Resolve 4 Devin Review issues on analog_acquisition
    1. Duplicate #PWR refs: renumbered 6 colliding GND symbols
    (#PWR36/37/38/40 duplicated across non-iso channels)
    to unique refs #PWR51-56
    2. Transformer footprint+MPN: T1-T3 assigned
    Wuerth 750315371 (SN6501-compatible center-tapped
    transformer), footprint from KiCad stock library
    3. Zero-length wires: removed 3 degenerate wires at
    hier_label positions for CO2/Temp/Hum channels
    4. Missing MPN/Distributor_PN: added to D19-D24
    (BAT54,115 Schottky) and C28-C30 (GRM21BR61C106KE15L
    10uF MLCC)
    ERC: Analog Acquisition = 0 violations, trace_net = 0 shorts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
    [analog_acquisition.kicad_sch]
2026-07-01 fix: reconcile refdes across schematic, BOM, and netlist doc
    BOM completely rewritten to match schematic refdes (source of truth):
    - U3=TPS3823 (was U12), U4/U7/U10/U11=MCP6002 (was U3 qty2)
    - U5/U8/U12=SN6501, U6/U9/U13=AMC1301 (replaces ADuM1250)
    - U14=HX711 (was U6), U15=MAX485 (was U13)
    - U16=PC817X2, U17=IR2104 (was U7), U18/U19=PC817X1
    - R3=WDI pull-up (was R_WDI), R4-R6=LED limits (was R_LED1-3)
    - R19/R20=I2C pull-ups (was R10/R11), R21=HX711 pull-up (was R12)
    - R24-R27=opto limits (was R13-R20), R28/C27/U20=CO2 PWM (was R21/C22/U3C)
    - All connectors shifted: J1=barrel jack, J2-J7=analog, J8-J16=digital
    - Added T1-T3, D19-D24, C28-C30 (isolated supply components)
    Netlist doc (07_KICA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
    [actuator_drivers.kicad_sch, digital_i2c.kicad_sch, nebula_qshield_bom.csv]
2026-07-06 fix: Actualizar dimensiones PCB a 100x100mm + análisis compactación
    - Actualizar dimensiones de 68.6x53.3mm a 100x100mm en README.md,
    01_PCB_ARCHITECTURE.md, y 06_PCB_LAYOUT_STACKUP.md
    - Actualizar mapas de zonas ASCII con layout actualizado para 100x100mm
    incluyendo componentes reales (AMC1301, SN6501, ISO1541, etc.)
    - Crear docs/08_MECHANICAL_ANALYSIS.md con análisis completo:
    * Cálculo de footprint areas por zona (158 componentes, 3541mm²)
    * Densidad de ocupación: 35.4% (cómoda, cabe en 100x100mm)
    * Perfil de alturas (BNC 25mm, TO-220 10mm, relays 7mm)
    * Cuellos de botella identificados con recomendaciones
    * Propuestas de optimización (D²PAK, MLCC vs electrolítico)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
2026-07-10 fix: Add post-buffer resistive divider for pH/ORP input range (±250mV AMC1301)
    [analog_acquisition.kicad_sch, nebula_qshield_bom.csv]
2026-07-10 ci: Run KiCad container as root (fixes EACCES in checkout)
2026-07-10 ci: Initialize stock KiCad lib tables so standard symbols resolve (fixes false lib_symbol_issues)
2026-07-10 fix(erc): remove floating stub wires + redundant overlapping wire (24->19)
    [actuator_drivers.kicad_sch, power_management.kicad_sch]
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2026-07-11 fix(buck): correct TPS54302 topology — EN UVLO, L1→SW, feedback, output caps
    - EN separated from VIN via UVLO divider (R34 100k / R35 18.2k) → ~8V startup,
    protects EN pin (abs-max 6V) from direct 12V
    - L1 moved from BOOT net to SW (was on wrong node — buck could not switch to output)
    - FB1.2 (ferrite) + input caps C3/C4 tied to filtered VIN; PWR_FLAG on VIN
    - Feedback divider completed: R1.1→5V_RAIL, R2 100k... value 24.9k→13.7k for ~4.95V
    (needed ≥4.5V for AMS1117-3.3 LDO input)
    - Output cap C6.1→5V_RAIL, LDO output cap C10.1→3V3_RAIL
    - Bootstrap C7 preserved between BOOT and SW
    - ERC 19→14 (lowered CI threshold accordingly)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
    [power_management.kicad_sch]
2026-07-12 fix(erc): clean remaining ERC violations in hierarchical schematics
    - Reconnect 5V_RAIL and 3V3_RAIL hierarchical labels in power_management.
    - Move MCU_WDI hierarchical label to U3 WDI and add R3 pull-up wiring.
    - Add PWR_FLAG sources for GND (power_management) and PGND (actuator_drivers).
    - Add 5V_RAIL PWR_FLAG in power_management.
    - Remove redundant PWR_FLAGS #FLG40 and #FLG41 from analog_acquisition.
    - Place no_connect markers on unused MAX485 U15 left-side pins.
    - Change HX711 AVDD pin type from power_out to power_in (library and digital sheet).
    - Change Arduino shield header 5V/3V3 pins from power_out to passive.
    - Achieve zero ERC violations in kicad-cli sch erc.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
    [actuator_drivers.kicad_sch, analog_acquisition.kicad_sch, digital_i2c.kicad_sch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]
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2026-07-12 feat(layout): initial placement of all 153 components on 4-layer 100x100mm board
    - Add tools/generate_initial_layout.py to build kicad/nebula_qshield.kicad_pcb
    from the netlist, with 4-layer stackup, rounded edge cuts, copper zones,
    and component placement in functional zones.
    - Pre-place J21, edge connectors, and large Actuator parts (U16, Q1/Q2/Q5, D14)
    so the greedy packer can place all 153 components without courtyard overlaps.
    - Add tools/fix_custom_footprints.py to add missing tstamp/uuid fields to
    custom footprints so pcbnew can load them.
    - Update kicad_dru custom rules to apply clearance/track constraints to
    tracks/vias/zones only (A.Type != 'pad'), avoiding false DRC viol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
    [nebula_qshield.kicad_pcb]
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2026-07-13 feat(routing): safe GND via and zone baseline for remaining unconnected items
    - Add tools/route_gnd_manual.py: resets GND zones to full/z-clearance,
    removes stubs, recreates GND vias with F.Cu/B.Cu pads, and drops vias
    on SMD GND pads clear of B.Cu obstacles.
    - Apply to kicad/nebula_qshield.kicad_pcb:
    * unconnected_items: 181 -> 132
    * no new clearance/shorting/tracks_crossing copper violations
    * replaces one pre-existing track_dangling warning with one
    isolated_copper warning in a 3V3_RAIL In2.Cu zone (pending manual
    3V3 routing in a follow-up PR).
    Manual F.Cu tracks for the remaining GND clusters will be handled in the
    next PR.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
    [nebula_qshield.kicad_pcb]
2026-07-13 feat(routing): manual GND via routing for U3/R35/C11 clusters and EN_UVLO detour
    - Reroute /Power Management/EN_UVLO on B.Cu and F.Cu to clear the U3 and
    R35 GND pads, keeping a safe clearance from MCU_NRST and MCU_WDI.
    - Replace and add 0.6/0.3 mm GND vias with per-net clearance, lowering
    unconnected_items from 132 to 123.
    - DRC copper violations unchanged (no new clearance/shorting/tracks_crossing
    items).
    [nebula_qshield.kicad_pcb]
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2026-07-17 feat(uno-q): add corrected Arduino UNO Q shield footprint and symbol
    - New footprint Arduino_UNO_Q_Shield with 32 pads (JANALOG 14 + JDIGITAL 18)
    and UNO R3/Q mounting holes at exact CAD drill positions.
    - New symbol Arduino_UNO_Q_Shield_Header_Corrected with UNO Q pin names,
    14+18 pins and footprint pointer.
    - Keep existing J21 footprint/symbol untouched to preserve DRC/ERC baseline.
    - Add UNO_Q_shield_proposal.md with J21 placement, keepout/cutout proposal
    and I2C/A4-A5 conflict note.
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2026-07-17 WIP: apply UNO Q re-architecture board changes
    - Replace J21 with Arduino_UNO_Q_Shield footprint at (5.08, 35.56)
    - Remap I2C_SDA/I2C_SCL to pins 31/32 (D20/D21)
    - Reserve A4/A5 (pins 13/14) for CO2_ADC/DO_ADC
    - Add R36/R37 4.7k pull-ups to /3V3_RAIL
    - Relocate D10, D11, F4, K1, K2, Q4, U16, U17, U19, U20 per plan
    - Add Edge.Cuts slots for USB-C, power button, power jack
    - Add Eco1.User keepout markers for JCTL, SPI2, QWIIC, USB-C/PMIC
    - Add local R_0603_1608Metric footprint
    - ERC: 0 violations; DRC: 1108 violations due to placement conflicts
    The 19 components that collide with the J21 courtyard (not the 10
    from the plan) prevent DRC=0; see UNO_Q_rearchitecture_report.md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
    [nebula_qshield.kicad_pcb]
2026-07-19 feat(re-arch): 100x120 mm UNO Q shield baseline with DRC-0 error level
    - Resize board outline to 100 mm x 120 mm with rounded corners and
    Edge.Cuts cutouts for UNO Q USB-C, power button, JCTL, SPI2/Qwiic access.
    - Replace J21 with Arduino_UNO_Q_Shield footprint at (5.08, 35.56) mm.
    - Remap I2C_SDA/I2C_SCL to pins 31/32 (D20/D21); A4/A5 kept for CO2_ADC/DO_ADC.
    - Add physical 4.7k pull-ups R36/R37 tied to 3V3 next to D20/D21.
    - Relocate K1/K2/U16/U17/U19/U20/D10/D11/Q4/F4 into the new board area.
    - Add Eco1.User keepout markers for the connector keepout zones.
    - DRC severity-error: 0 violations (365 unconnected items remain for routing).
    - ERC: 0 violations.
    - Include helper scripts: prep_1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
    [nebula_qshield.kicad_pcb]
2026-07-20 feat(schematic): finalize UNO Q J21 symbol, I2C pull-ups and wiring
    - hmi_connectors.kicad_sch: migrate J21 to Arduino_UNO_Q_Shield_Header_Corrected
    (32 pins), route I2C_SDA/I2C_SCL to D20/D21 (pins 31/32), reserve A4/A5
    for CO2_ADC/DO_ADC, add R36/R37 4.7k pull-ups to 3V3_RAIL, remove
    duplicate/legacy wiring, embed Device:R lib symbol.
    - nebula_symbols.kicad_sym: set +3V3 and +5V J21 pins to passive to avoid
    ERC power-output conflicts with PWR_FLAG/regulators.
    - ERC clean (0 violations). DRC error-level clean (365 unconnected baseline
    pending routing).
    [hmi_connectors.kicad_sch]
2026-08-10 fix(grounding): unify AGND/PGND into GND, migrate CI to KiCad 10.0.5 — ERC 14→0
    AGND and PGND were fully isolated nets with no path to GND, so the actuator
    return path (MOSFET sources, opto emitters, gate-driver COM, flyback diodes,
    terminal blocks) and the CO2/humidity sensor returns were floating. Merge them
    into the single global GND net per the unified-grounding decision: one
    continuous plane on layer 2, star grounding realised through placement and
    local vias rather than split nets.
    The isolated domains are untouched — GND_ISO_PH/ORP/DO (AMC1301 + SN6501
    transformer) and GND_ISO (ISO1541) stay floating, since the galvanic barrier
    lives in the isolators, not in a second ground pla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
    [actuator_drivers.kicad_sch, analog_acquisition.kicad_sch, hmi_connectors.kicad_sch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]
2026-08-10 feat(rs485): SC16IS740 I2C-UART bridge + realign J21 pin map to firmware
    RS485 Modbus had no digital interface: U15's RO/~RE/DE/DI were carrying
    no-connect flags, so ERC stayed silent while the transceiver was unusable.
    The UNO Q has no free UART TX/RX pair (USART1 is the HMI, the alternate
    pairs land on analog pins), so Modbus now hangs off the I2C bus through an
    SC16IS740 bridge and coexists with the HMI.
    - U22 SC16IS740 on I2C at 0x4D (A0/A1 low), Y1 1.8432 MHz + C31/C32,
    C33 decoupling, R38 pull-up on the open-drain ~IRQ, exported to J21 D10
    - U23 SN74LVC1G04 inverts ~RTS into DE/~RE. The bridge leaves ~RTS high
    after POR, which would enable the driver and seize the multidrop bus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
    [digital_i2c.kicad_sch, hmi_connectors.kicad_sch, nebula_qshield.kicad_sch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]
2026-08-10 docs(sch): Phase 0 — validate and freeze J21 Insight pinout
    - Confirm J21 pins 9-32 match N_A_UNOQ sketch.ino (A0-5, D0-13, D20/21 I2C).
    - D4 assigned to MCU_WDI; firmware must toggle D4 for TPS3823 watchdog.
    - Update roadmap Phase 0 checklist and fix schematic title-block comments for analog/HMI header.
    - ERC --severity-all = 0 after edits.
    [analog_acquisition.kicad_sch, hmi_connectors.kicad_sch]
2026-08-10 docs(uno-q): add UNO Q form-factor reference, fix J21 footprint, sync board, fix Edge.Cuts
    - Add docs/UNO_Q_FORM_FACTOR.md as the immutable UNO Q form-factor reference
    for the Nebula Q-Shield (headers, mounting holes, keepouts/cutouts).
    - Correct kicad/lib/nebula_footprints.pretty/Arduino_UNO_Q_Shield.kicad_mod
    digital-header pad numbering (D21/SCL pin 32 left -> D0 pin 15 right).
    - Sync kicad/nebula_qshield.kicad_pcb J21 pad nets from schematic netlist:
    I2C_SDA/I2C_SCL -> pins 31/32, A4/A5 -> CO2_ADC/DO_ADC, etc.
    - Refill copper zones and convert board/project to KiCad 10.0.5 format.
    - Remove nested Edge.Cuts polygon that caused invalid_outline DRC error.
    - Update roadmap, audit, READ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
    [nebula_qshield.kicad_pcb]
2026-08-10 feat(pcb): Fase 1 — sincronización esquemático/PCB KiCad 10
    - Forward-annotation headless del netlist al PCB usando tools/apply_phase1_minimal.py y tools/sexpr.py
    - Trae los 7 footprints faltantes del puente RS485: U22, U23, Y1, C31-C33, R38
    - Sincroniza nets de U15 (VCC a 3V3, RO/DI/DE/~RE a RS485_*), J21 y pull-ups R36/R37
    - Unifica etiquetas AGND/PGND a GND en el PCB
    - Preserva zonas de cobre, Edge.Cuts y keepouts mecánicos
    - Validación: ERC 0 violaciones, DRC error-level 0 violaciones
    - Actualiza docs/INSIGHT_FABRICATION_ROADMAP.md con Fase 1 completada
    [nebula_qshield.kicad_pcb]
2026-08-10 fix(pcb): Fase 2 — resolve Edge.Cuts / J21 silkscreen conflict and Devin Review findings
    - Remove J21 F.SilkS rectangle from PCB and library to fix
    silk_edge_clearance / silk_overlap warnings against interior Edge.Cuts slots.
    - Keep F.Fab outline and F.CrtYd courtyard; update library footprint to match
    board copy (remove_unused_layers no, duplicate_pad_numbers_are_jumpers no).
    - Clean stray closing paren in Edge.Cuts section.
    - Fix Devin Review PR #40 findings:
    - sexpr.py net regex handles (net <idx> "NAME") form.
    - compare_pcb_to_netlist.py reports stale nets, extra/missing footprints, missing pins.
    - apply_phase1_minimal.py resolves project lib first and raises RuntimeError on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
    [nebula_qshield.kicad_pcb]
2026-08-10 docs: actualizar baseline de DRC warning tras limpiar Edge.Cuts
    - Corregir bitácora y 08_MECHANICAL_ANALYSIS: el DRC --severity-warning
    reporta 447 warnings (silk_overlap, silk_over_copper, silk_edge_clearance,
    isolated_copper, lib_footprint_mismatch), no 1. Estos son baseline del
    board no ruteado y placement denso; error-level sigue en 0.
2026-08-10 fix(tools,bom): address Devin Review comments on PR #41
    - tools/sexpr.py: drop stale numeric net index when renaming pad nets to
    avoid inconsistent (net <idx> "NEW_NAME") pairs.
    - tools/compare_pcb_to_netlist.py: propagate main() return code with sys.exit().
    - docs/04_BOM_PRODUCTION.md:
    - Fix C33 Digi-Key PN to 1276-1001-1-ND (matches MPN used elsewhere).
    - Update digital block line count (18) and total (153) in summary.
    - Update tier population counts (98/134/153 de 153) and list RS485 bridge
    components for Insight/Signature.
    - Update J21 description to Arduino UNO Q shield header, 32 pins.
    Validation: kicad-cli pcb drc --severity-error = 0; kicad-cli sch erc --severity-all =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
2026-08-10 fix(sch,pcb): Fase 3 — reparar nets críticas y paridad T1/T2/T3
    - Corrige conexiones secundarias de T1/T2/T3: *_SEC_B pasa del pin 7 al
    pin 6 del footprint Wuerth 750315371 (6 pads); pin 7 no-conectado.
    *_SEC_A en pin 4, GND_ISO_* en pin 5.
    - Actualiza pad nets en PCB para T1/T2/T3 según netlist corregido.
    - Marca items de Fase 3 completados en la bitácora.
    - tools/compare_pcb_to_netlist.py: ignora pines con pintype no_connect y
    nets 'unconnected-' para evitar falsos positivos de paridad.
    ERC: 0 violaciones. DRC error-level: 0 violaciones, 394 desconectados
    baseline. Paridad esquemático/PCB: 0 problemas.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
    [analog_acquisition.kicad_sch, nebula_qshield.kicad_pcb]
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2026-08-10 fix(tools,sch,docs): handle expanded sexpr in HMI sheet and correct tier counts
    - Update tools/apply_tier_dnp4.py regexes to be whitespace-tolerant so they
    work with both compact and expanded KiCad s-expression styles.
    - Update tools/list_actual_components.py to use the same top-level block parser
    and whitespace-tolerant property extraction, so components on
    kicad/hmi_connectors.kicad_sch (J20, J21, R36, R37, D15-D18) are included.
    - Regenerate kicad/actual_components.json and kicad/tier_dnp_mapping.json.
    - Apply DNP properties to kicad/hmi_connectors.kicad_sch (all NO).
    - Update docs/04_BOM_PRODUCTION.md tier counts to 88/137/146 of 163 unique
    placements and add the missing HMI comp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
    [hmi_connectors.kicad_sch]
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2026-08-10 docs(kicad): strengthen SSH setup guide (Ed25519, passphrase, no ssh-rsa downgrade)
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2026-08-10 fix(pcb): extend GND zones (B.Cu and In1.Cu) to full 100 × 120 mm board outline
    [nebula_qshield.kicad_pcb]
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2026-08-10 fix(pcb): extend /12V_RAIL split-plane to full 100 × 120 mm board
    [nebula_qshield.kicad_pcb]
2026-08-11 feat(pcb): Fase 4 power routing baseline
    - Add 2 M3 case mounting holes (H1, H2) in DRC-clean positions.
    - Import FreeRouting pass; manually fix /12V_RAIL route near C1 to
    clear C1 GND pad and MCU_NRST net.
    - Adjust /I2C_SDA trace near cutout to meet copper edge clearance.
    - DRC severity-error: 0 violations, 115 unconnected items remaining.
    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
    [nebula_qshield.kicad_pcb]
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2026-08-12 feat(pcb): ruteo manual GND y stubs — DRC 0, 72 unconnected, vía 0.5/0.2, fix PUMP_DIR
    [nebula_qshield.kicad_pcb]
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2026-08-12 Fase 6: apply Spark short-pair routing, close U22 GND, add close_pairs_v7.py; DRC 0, 44 unconnected
    [nebula_qshield.kicad_pcb]
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2026-08-13 docs: agregar CLAUDE.md y notas de tooling KiCad para futuros agentes
    Destila los gotchas de pcbnew/kicad-cli descubiertos en Fase 6 (resolucion
    de .kicad_pro/.kicad_dru por basename, ancho preferido vs minimo real por
    netclass, GetWidth() sin capa cuelga el proceso, pares Zone-Zone
    fantasma en DRC, courtyard real vs GetBoundingBox, tolerancia de
    clearance) en un lugar que se carga solo en cada sesion futura, en vez de
    quedar enterrado en el historial de commits.
